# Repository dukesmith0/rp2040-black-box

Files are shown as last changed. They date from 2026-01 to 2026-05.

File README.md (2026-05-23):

# RP2040 Black Box

Flight data logging system using an Adafruit RP2040 microcontroller to capture IMU, GPS, barometric, and magnetometer data at up to 200Hz with Mahony AHRS filtering.

## Hardware

| Component | Description |
|---|---|
| Adafruit Feather RP2040 Adalogger | Main board with SD card slot |
| Adafruit BMP390 | Barometric altimeter (50Hz) |
| Adafruit LSM6DSOX | 6-DOF accelerometer/gyroscope (208Hz) |
| Adafruit LIS3MDL | 3-axis magnetometer (155Hz) |
| Adafruit Mini GPS PA1010D | GPS module (10Hz) |

### Hardware Guides
- [Adafruit Feather RP2040 Adalogger](https://learn.adafruit.com/adafruit-feather-rp2040-adalogger/overview)
- [Adafruit BMP390](https://learn.adafruit.com/adafruit-bmp388-bmp390-bmp3xx/overview)
- [Adafruit Mini GPS PA1010D](https://learn.adafruit.com/adafruit-mini-gps-pa1010d-module/overview)
- [Adafruit LSM6DSOX + LIS3MDL 9-DOF](https://learn.adafruit.com/st-9-dof-combo/overview)

### Enclosure

The second enclosure revision features a full case for better protection and improved battery mounting.

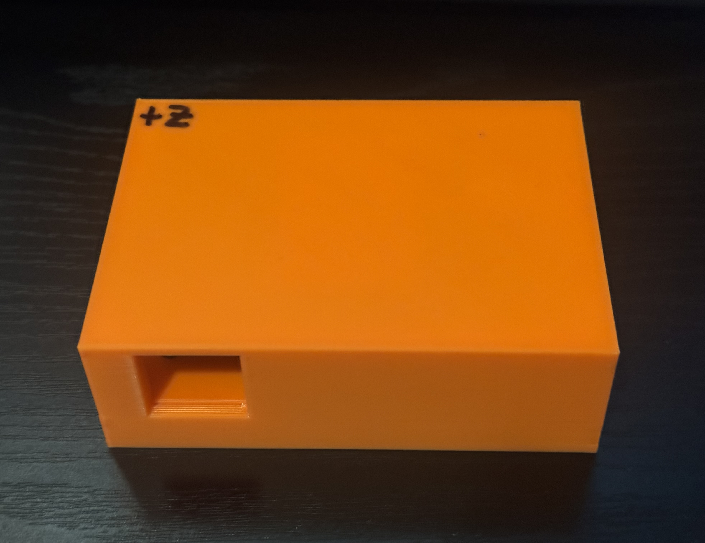
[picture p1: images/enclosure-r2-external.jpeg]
Enclosure R2 external

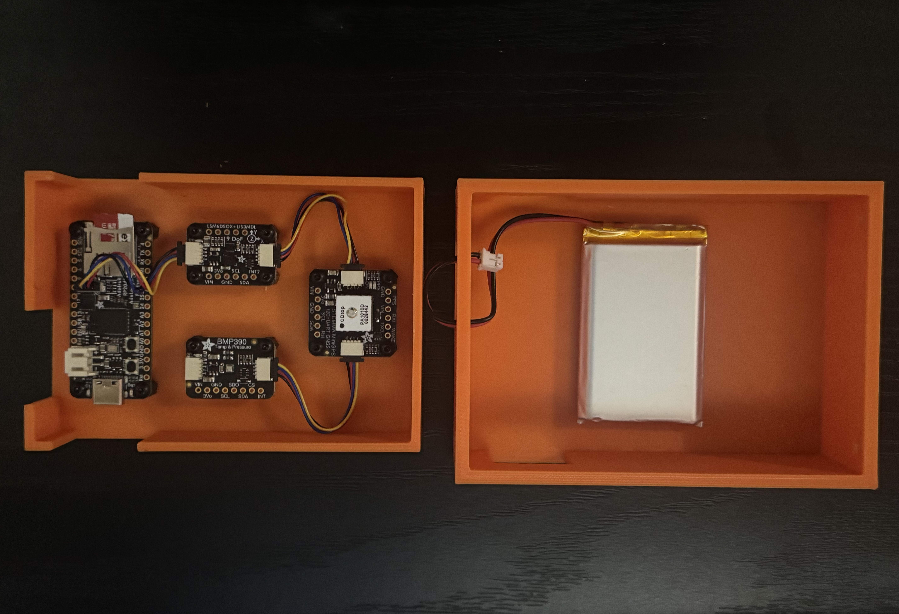
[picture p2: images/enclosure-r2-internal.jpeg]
Enclosure R2 internal


| Part | Quantity |
|---|---|
| M2.5 heat inserts | 14 |
| M2.5 6mm standoffs | 12 |
| M2.5 6mm screws | 12 |
| M3 heat inserts | 4 |
| M3 6mm standoffs | 4 |
| M3 6mm screws | 4 |
| 50mm STEMMA QT cable | 3 |
| 32GB SD card (FAT32) | 1 |
| 3.7V 2000mAh LiPo battery (2-pin JST-PH) | 1 |
| Hot glue | - |

### Estimated Cost

| Item | Est. Price |
|---|---|
| Adafruit Feather RP2040 Adalogger | $14.95 |
| Adafruit BMP390 | $10.95 |
| Adafruit LSM6DSOX + LIS3MDL 9-DOF IMU | $19.95 |
| Adafruit Mini GPS PA1010D | $29.95 |
| STEMMA QT 50mm cables (×3) | $2.85 |
| 32GB microSD card | ~$8 |
| 3.7V 2000mAh LiPo battery | $12.50 |
| 3D printed enclosure (PLA filament) | ~$3 |
| M2.5/M3 hardware (heat inserts, standoffs, screws) | ~$10 |
| Hot glue | ~$1 |
| **Total** | **~$113** |

> Prices based on Adafruit retail (single-unit) as of early 2026. SD card and hardware prices vary by vendor.

---

## Getting Started

### Arduino Setup

Add this URL to Arduino IDE > File > Preferences > Additional Boards Manager URLs:
```
https://github.com/earlephilhower/arduino-pico/releases/download/global/package_rp2040_index.json
```

Install **Raspberry Pi Pico/RP2040/RP2350** by Earle F. Philhower, III

Select board: **Tools > Boards > Raspberry Pi Pico RP2040/RP2350 > Adafruit Feather RP2040 Adalogger**

> Note: If no serial port appears, that's normal - RP2040 uses USB bootloader. A port will appear after first upload.

### Arduino Libraries

Install via Library Manager (Tools > Manage Libraries):

| Library | Purpose |
|---|---|
| **SdFat** | SD card operations |
| **Adafruit BMP3XX** | BMP390 altimeter |
| **Adafruit GPS Library** | PA1010D GPS |
| **Adafruit LIS3MDL** | Magnetometer |
| **Adafruit LSM6DSOX** | Accelerometer/Gyroscope |
| **Adafruit AHRS** | Mahony sensor fusion |
| **Adafruit Unified Sensor** | Common sensor interface (dependency) |
| **Adafruit BusIO** | I2C/SPI helper (dependency) |

> **Important:** This project uses the `SdFat` library (not the standard Arduino `SD.h`) for proper RP2040 Adalogger hardware support.

### SD Card

**Hardware configuration:**
- **CS Pin:** 23 (NOT pin 10!)
- **SPI Bus:** SPI1 @ 16MHz
- **Library:** SdFat (configured automatically in firmware)

**Requirements:**
- Format: FAT32 with 4KB allocation unit size
- Works with most SD/SDHC cards

**Troubleshooting:**
If SD initialization fails, check that the card is inserted and formatted as FAT32 with 4KB allocation units. Try cleaning the contacts or using a different card. The firmware retries 5 times automatically. Use `firmware/test/sd_card_tester/` to diagnose issues.

---

## Firmware

### quat_datalogger

Dual-core flight data logger with real-time AHRS filtering and signal processing.

Serial Data

**Core 0** reads sensors and logs to SD at 100Hz. **Core 1** runs the Mahony AHRS filter at 200Hz.

**Signal processing pipeline:**
- Adaptive Mahony filter (Kp ramps 10.0 → 1.0, Ki = 0.008 for drift correction)
- Sensor calibration: magnetometer hard/soft iron, gyro auto-cal at boot, accelerometer offsets
- Altitude: BMP390 hardware IIR → software low-pass filter → GPS complementary filter
- Auto sea-level pressure calibration from first good GPS fix
- GPS quality rejection (min satellites, max HDOP) with low-pass filtered speed/heading
- Automatic file splitting every ~1 GB to stay under FAT32 4 GB limit

Calibration constants are loaded from `calibration.cfg` on the SD card at boot (see [Calibration](#calibration)). Filter tuning parameters are editable at the top of the firmware file.

### Calibration Sketches

Two standalone sketches in `firmware/calibration/` for computing sensor calibration values:

- **magnetometer_calibration**: Streams `Raw:` / `Uni:` data over serial in the format expected by [MotionCal](https://www.pjrc.com/store/prop_shield.html). Rotate the device in all orientations until the sphere fills in, then copy the hard/soft iron values into `calibration.cfg`.
- **accelerometer_calibration**: Interactive serial-guided 6-position calibration. Prompts you through each orientation, collects samples, and writes the computed offsets directly to `calibration.cfg` on the SD card.

### diagnostic

Serial and sensor diagnostic tool that tests each I2C sensor individually with detailed bus diagnostics. Upload and open Serial Monitor at 115200 baud to verify all sensors are detected and responding correctly.

### sd_card_tester

Diagnostic tool for verifying SD card compatibility. Tests initialization, read/write, and speed benchmarking.

---

## Data Format

**Output:** 20-column CSV at 100Hz

| Column | Description | Units |
|---|---|---|
| ms | Timestamp | milliseconds |
| qw, qx, qy, qz | Orientation quaternion | - |
| ax, ay, az | Acceleration | m/s² |
| gx, gy, gz | Angular velocity | rad/s |
| mx, my, mz | Magnetic field | uT |
| alt | Filtered altitude | meters |
| gps_fix | GPS lock status | 0/1 |
| lat, lon | GPS coordinates | decimal degrees |
| speed | Filtered GPS speed | knots |
| heading | Filtered GPS heading | degrees |

**File naming:** Timestamps use UTC from the GPS module's battery-backed RTC.
- GPS time available: `20260130_143022_0.csv`, `..._1.csv`, `..._2.csv`
- GPS time unavailable: `log0_0.csv`, `log0_1.csv`, ...
- Header: `# Start: YYYY-MM-DDTHH:MM:SS UTC`

---

## Calibration

Calibration values are stored in a `calibration.cfg` file on the SD card. The firmware reads this file at boot and applies the values automatically. If the file is missing, compiled defaults (zeros / identity) are used.

### 0. Gyroscope Bias (automatic)

The firmware averages 500 samples at boot while stationary. Keep the device still for 5 seconds after power-on. The computed bias is printed to serial.

To skip the wait, note the printed values and hardcode them in the firmware:
```cpp
static const bool GYRO_AUTO_CAL = false;
static float gyro_bias[3] = { -0.0023f, 0.0041f, -0.0012f };
```

### 1. Magnetometer Hard/Soft Iron (critical for heading accuracy)

This is the most important calibration. Without it, heading (yaw) will be unreliable.

1. Upload `firmware/calibration/magnetometer_calibration/` to the board
2. Open [MotionCal](https://www.pjrc.com/store/prop_shield.html) and select the serial port
3. Slowly rotate the device through all orientations (figure-8 pattern) until the sphere fills in
4. Read the values from MotionCal and add them to a new file called `calibration.cfg` in the root of the SD card, using this format:
```
mag_hard_iron = <X>, <Y>, <Z>
mag_soft_iron = <M00>, <M01>, <M02>, <M10>, <M11>, <M12>, <M20>, <M21>, <M22>
```

Do this calibration with the device in its final enclosure. Nearby metal magnets, and mechanical stresses may affect the result.

### 2. Accelerometer Offsets

1. Upload `firmware/calibration/accelerometer_calibration/` to the board
2. Open Serial Monitor at 115200 baud
3. Follow the prompts: place the device in each of 6 orientations (X up/down, Y up/down, Z up/down) and press Enter
4. Hold the device perfectly still during each 2-second measurement
5. The computed offsets are automatically saved to `calibration.cfg` on the SD card

The sketch preserves any existing entries (e.g., magnetometer values) in the config file.

### 3. Sea-Level Pressure (automatic)

The firmware auto-calibrates from the first good GPS fix. No action needed.

For manual override, add to `calibration.cfg`:
```
sea_level_hpa = 1018.5
```

And optionally disable auto-cal in the firmware:
```cpp
static const bool BARO_GPS_AUTO_CAL = false;
```

### 4. Validation

After calibrating, run these checks on the quat_datalogger.ino firmware.

| Test | Procedure | Expected Result |
|---|---|---|
| Static | Place flat and still for 30s after boot | Quaternion settles to ~[1, 0, 0, 0] |
| Rotation | Rotate 90° and return | Quaternion returns to original value |
| GPS walk | Walk a known rectangle outdoors | Lat/lon tracks your path, altitude is stable |

---

## Visualization

### Flight Visualizer (Streamlit)

Interactive web-based visualization.

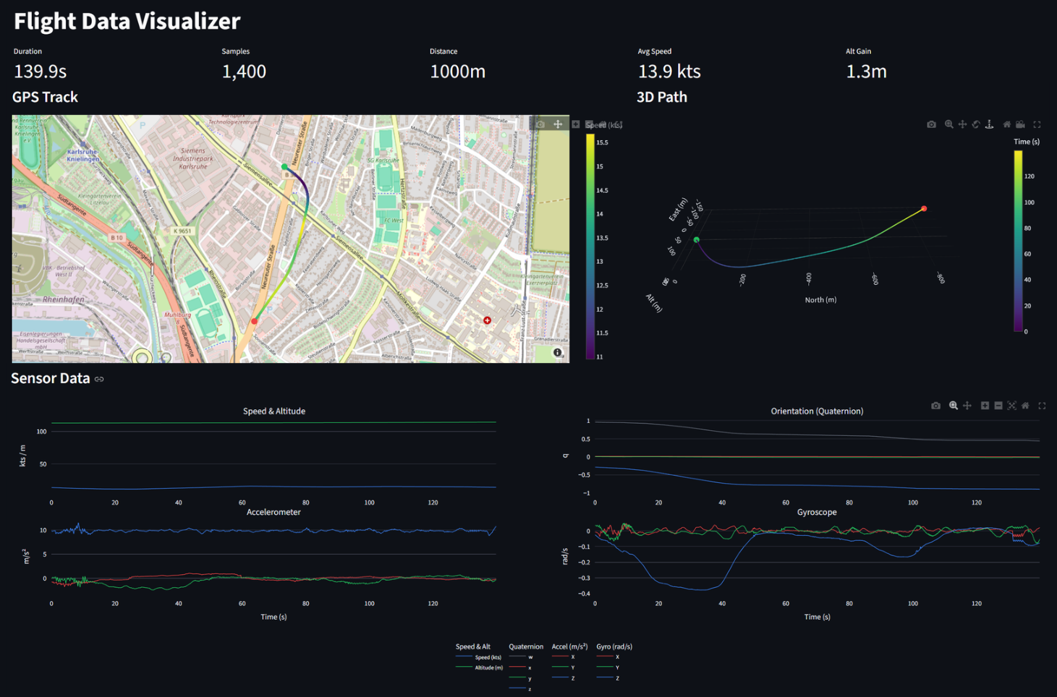
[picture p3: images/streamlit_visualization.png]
Streamlit Visualization


```bash
pip install streamlit pandas numpy plotly scipy
cd software/flight_visualizer
streamlit run app.py
```

Live demo: **[rp2040-fdr-visualizer.streamlit.app](https://rp2040-fdr-visualizer.streamlit.app/)**

### Trajectory Visualizer (MATLAB)

Desktop visualization with satellite map overlays, dead reckoning, and sensor charts. Requires MATLAB with **Navigation Toolbox** (`quaternion`, `rotateframe`).

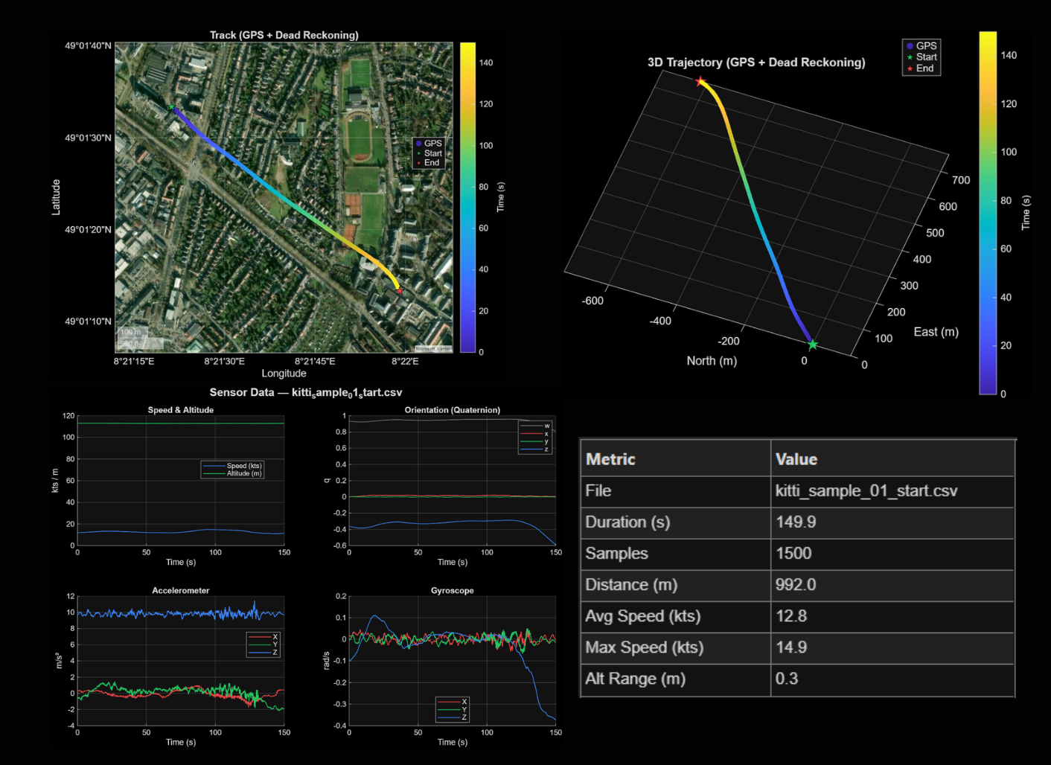
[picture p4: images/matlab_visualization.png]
Matlab Visualization


```
Open MATLAB, navigate to software/matlab-visualizer/, run trajectoryvisualizer.m
```

A file picker dialog opens. Select any 20-column CSV from `data/samples/` or from the SD card.

**Displays:**
- Summary statistics popup (duration, distance, speed, altitude range)
- 2D GPS + dead-reckoned track on satellite basemap (time-gradient colored, circle markers for GPS, diamond markers for dead reckoned)
- 3D trajectory with gradient-colored line (North/East/Altitude in meters)
- 4-panel sensor charts: Speed & Altitude, Quaternion, Accelerometer, Gyroscope

When GPS fix is lost, the visualizer dead-reckons position by rotating body-frame acceleration to NED using the quaternion, subtracting gravity, and integrating velocity/position. Barometric altitude is used for the vertical axis throughout.

### Live Orientation Visualizer (MATLAB)

Real-time 3D orientation display from live serial data. Connects to the RP2040 over USB and renders orientation using `poseplot`. Requires MATLAB with **Navigation Toolbox** and R2019b+ (`serialport`).

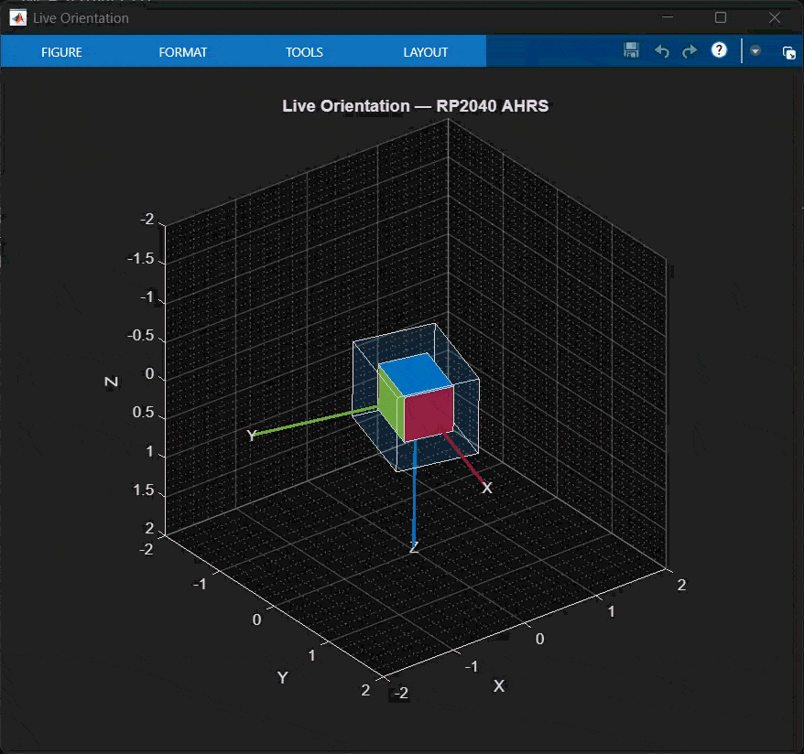
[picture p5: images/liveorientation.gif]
Live Orientation


```
Open MATLAB, navigate to software/matlab-visualizer/, run liveorientationvisualizer.m
```

Select a serial port and baud rate (default 115200) when prompted. The figure updates in real time as the device streams quaternion data. Close the figure window to disconnect.

---

## Future Plans

### Enclosure
- Ruggedize with TPU secondary enclosure for crash survivability

### Hardware
- Upgrade GPS module to use a larger antenna for better signal
- Design custom PCB integrating RP2040 and all sensors onto a single board
- Add Bluetooth for wireless flight data streaming
- **Consider BNO085 IMU**: Replace LSM6DSOX + LIS3MDL with BNO085 for onboard hardware EKF fusion, reducing CPU load with hardware-accelerated quaternion output and automatic calibration

### Power & Monitoring
- Optimize battery usage and create power consumption metrics
- Add internal telemetry: battery life, board temperature

### Software
- Add Simulink visualization for real-time 3D flight simulation and analysis

---

## Previous Iterations

### Enclosure R1

The first enclosure prototype. Open-top design with standoff-mounted boards.

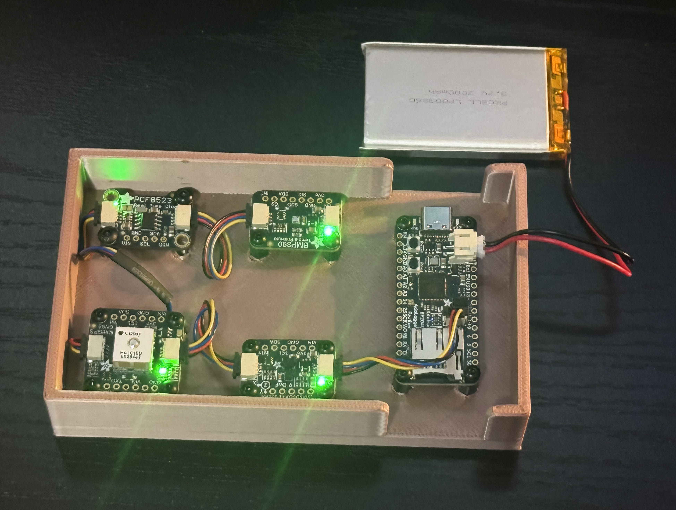
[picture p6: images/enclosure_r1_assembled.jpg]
Enclosure R1 assembled


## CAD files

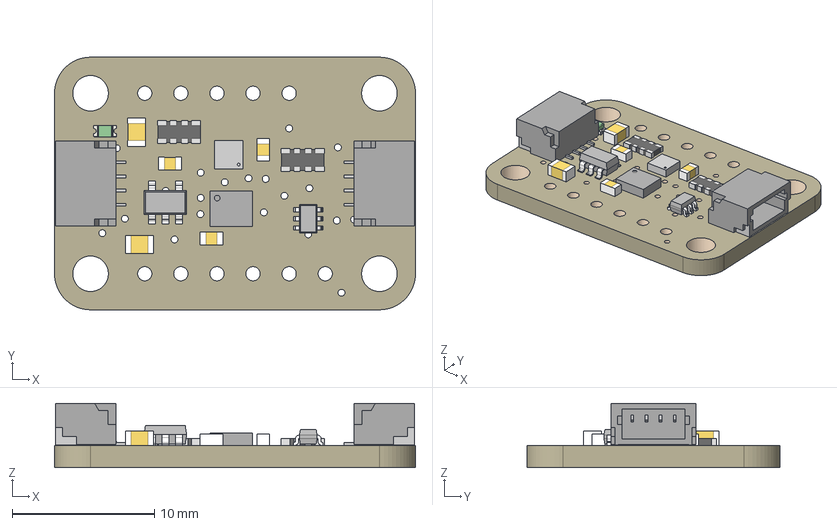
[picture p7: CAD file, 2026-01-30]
hardware/boards/4517_LSM6DSOX_LIS3MDL.step
25.4 x 17.8 x 4.53 mm
Board
10uF x 2
AP2112K-3.3
1uF x 3
10K x 2
BSS138
STEMMA_I2C_QT x 2
GREEN
LIS3MDL
LSM6DSOX

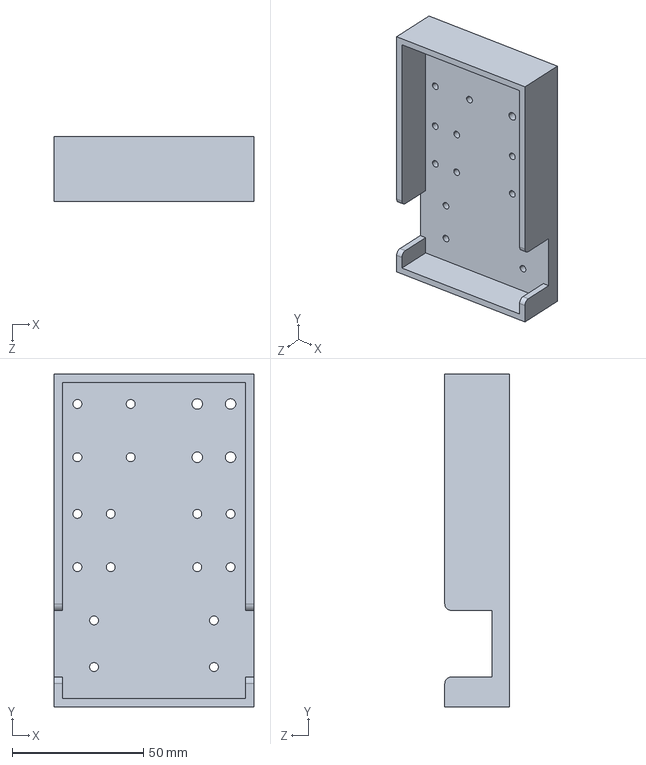
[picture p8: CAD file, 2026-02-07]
hardware/enclosure-r1/enclosure-r1.STEP
76.2 x 127.0 x 24.6 mm

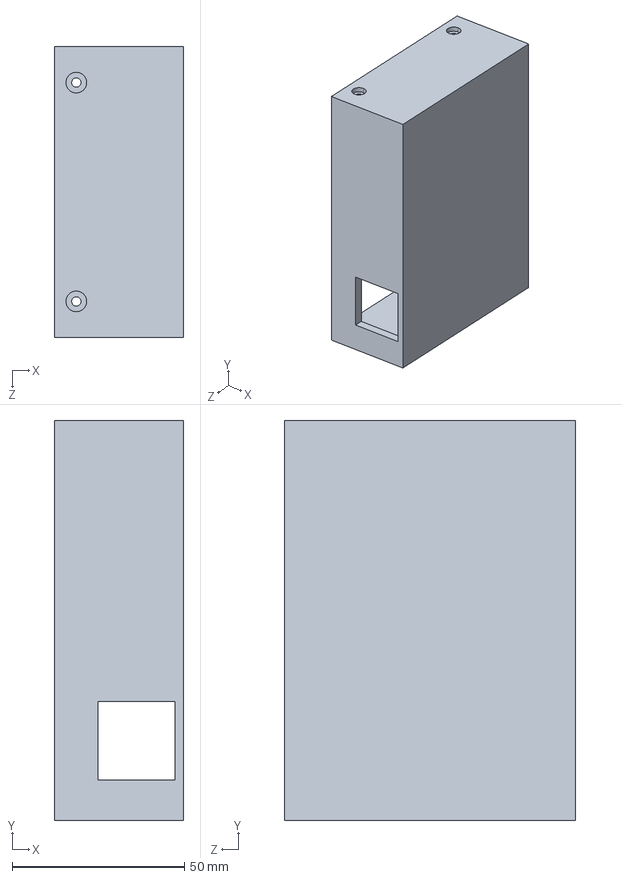
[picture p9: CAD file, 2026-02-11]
hardware/enclosure-r2/top.STEP
37.5 x 116.1 x 84.3 mm

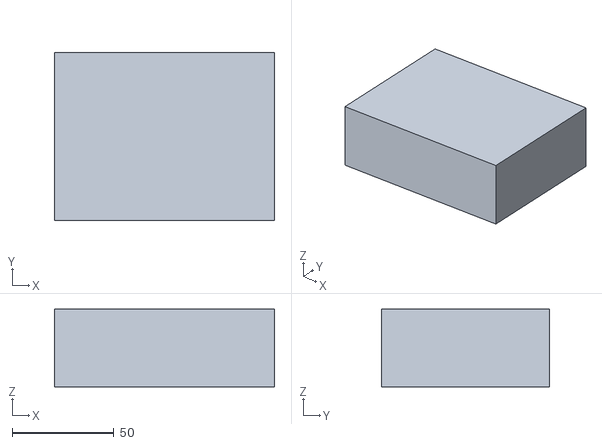
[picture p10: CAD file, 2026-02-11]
software/matlab-visualizer/visualizer_placeholders/enclosure_r2_ph.stl
107.9 x 82.6 x 38.1

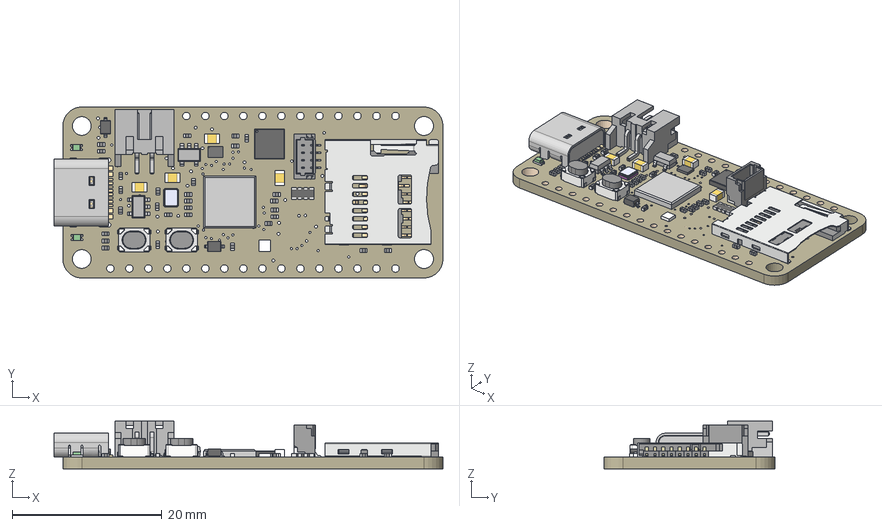
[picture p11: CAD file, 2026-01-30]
hardware/boards/5980_Feather_RP2040_Adalogger.step
52.0 x 22.9 x 6.37 mm
Board
10uF/16V x 4
ORANGE x 2
47K x 29
RKB2 x 2
RT9080-3.3
JSTPH
MCP73831T-2ACI/OT
WS2812B_SK6805_1515
8MB QSPI
PMEG2020AEA
DMG3415UFY
USB Type C
RP2040_QFN56
12MHz/12pF
1N5819
STEMMA_I2C_QTRA
MicroSD
47K_1

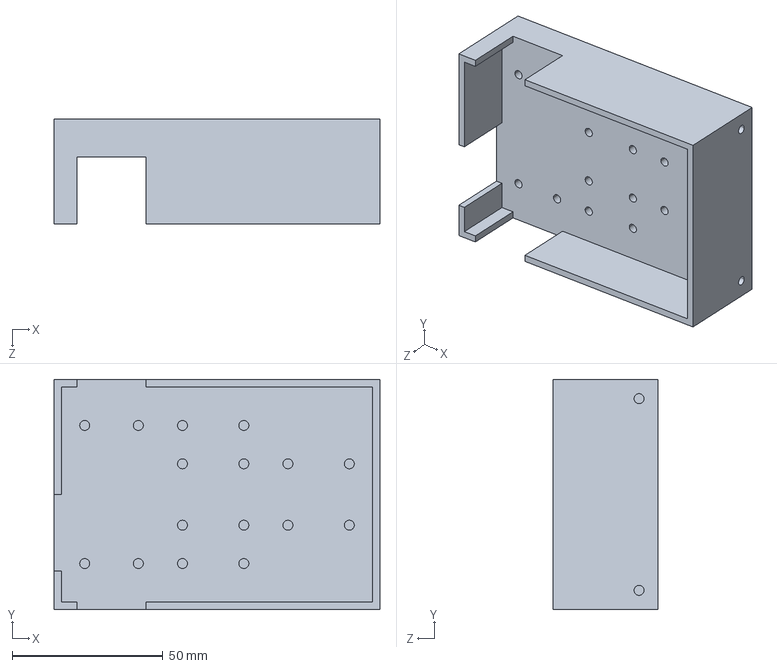
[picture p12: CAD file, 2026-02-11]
hardware/enclosure-r2/base.STEP
107.9 x 76.2 x 34.9 mm

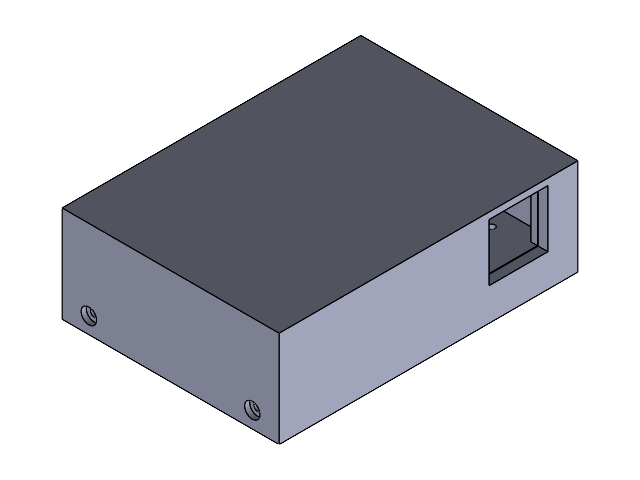
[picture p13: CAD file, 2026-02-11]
hardware/enclosure-r2/assembly.SLDASM
base
top

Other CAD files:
hardware/boards/4816_BMP390_QT.step
hardware/enclosure-r1/enclosure-r1.SLDPRT
hardware/enclosure-r2/base.SLDPRT
hardware/enclosure-r2/top.SLDPRT

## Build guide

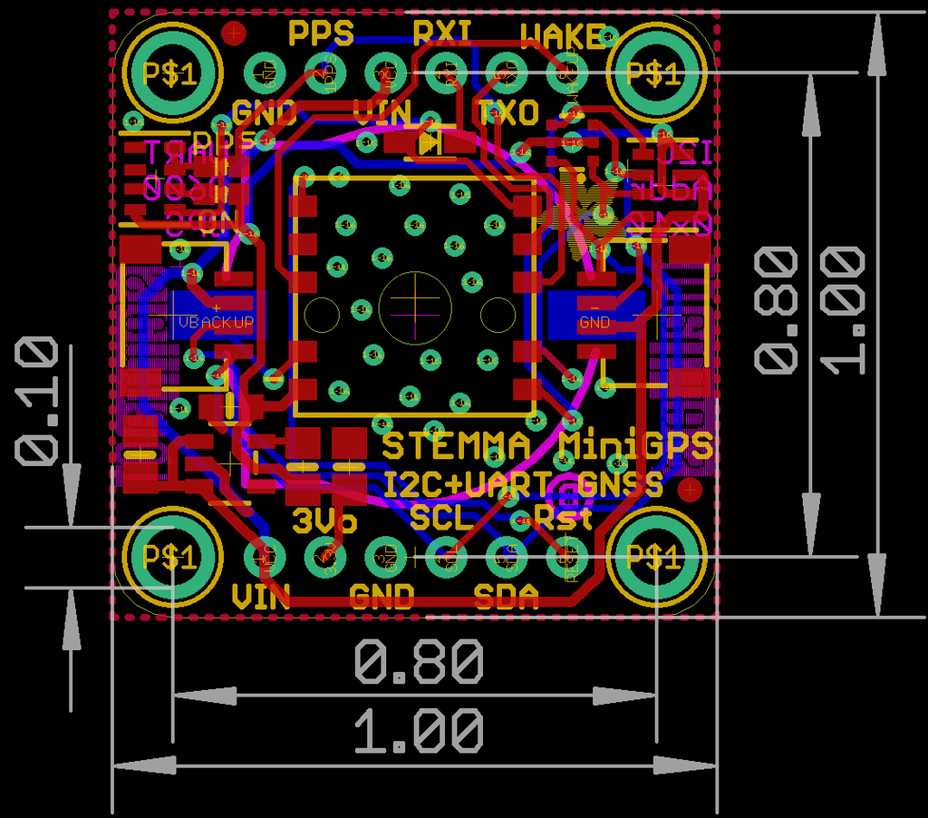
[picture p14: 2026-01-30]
hardware/boards/mini_gps_PA1010D_fab_print.png

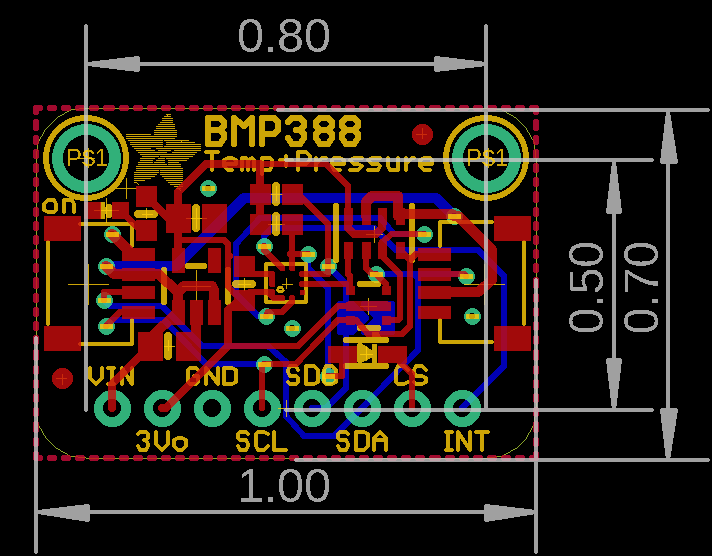
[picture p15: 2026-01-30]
hardware/boards/barometer_altimeter_BMP390_fab_print.png

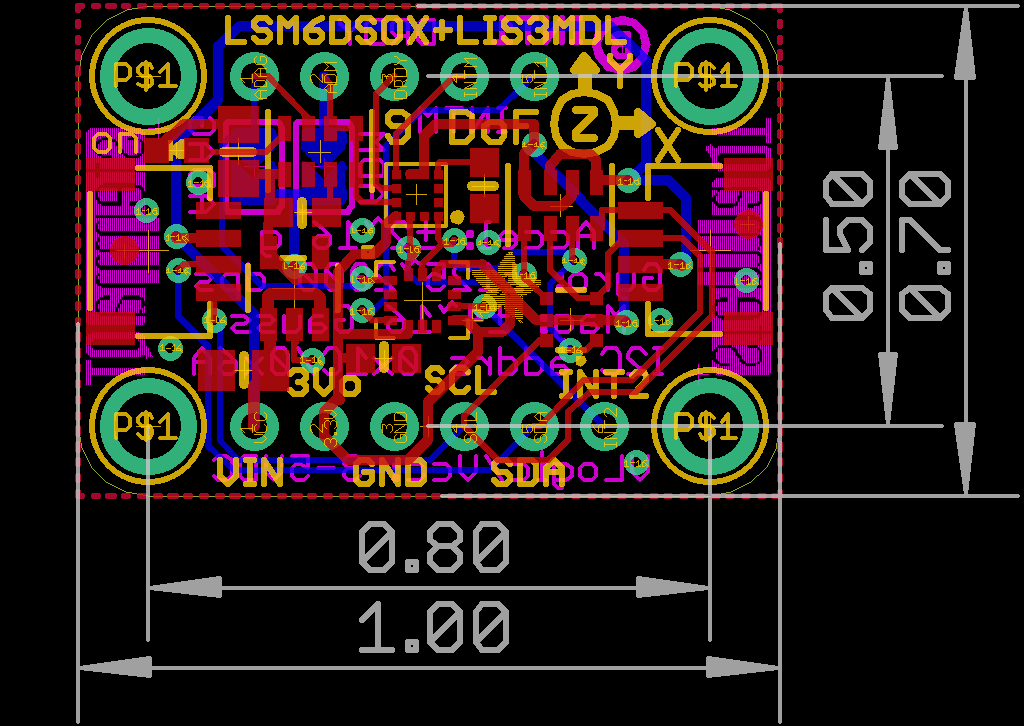
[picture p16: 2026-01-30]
hardware/boards/imu_LSM6DSOX_LIS3MDL_fab_print.png

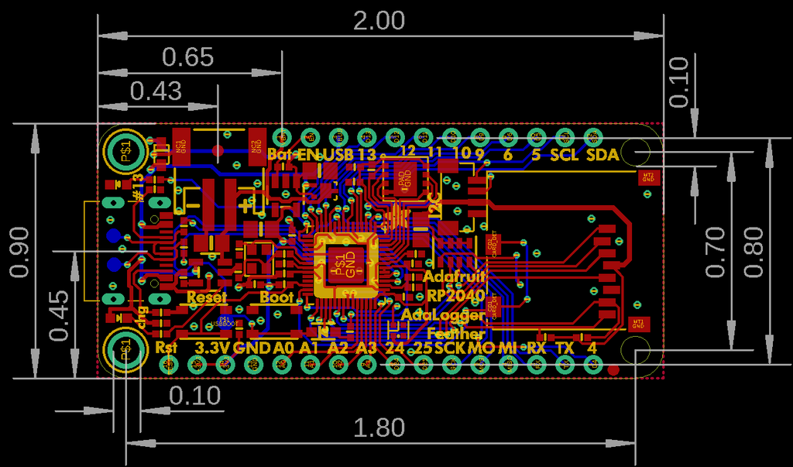
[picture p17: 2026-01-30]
hardware/boards/feather_rp2040_adalogger_fab_print.png

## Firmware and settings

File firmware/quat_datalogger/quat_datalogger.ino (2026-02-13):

/*
  RP2040 Black Box — Mahony AHRS Data Logger (Dual-Core)

  General architecture and output format:

  Core 0: Sensor reading, complementary filtering of altitude/GPS, data logging to SD
  Core 1: Mahony AHRS filter with adaptive gain

  CSV output (20 columns):
    ms, qw, qx, qy, qz, ax, ay, az, gx, gy, gz, mx, my, mz, alt, gps_fix, lat, lon, speed, heading

  File splitting: Creates new CSV every ~1 GB to stay under FAT32 4 GB limit.
*/

#include <Wire.h>
#include <SPI.h>
#include "SdFat.h"
#include <Adafruit_BMP3XX.h>
#include <Adafruit_LSM6DSOX.h>
#include <Adafruit_LIS3MDL.h>
#include <Adafruit_GPS.h>
#include <Adafruit_AHRS.h>

// ============================================================
//  CALIBRATION CONSTANTS — Edit these post calibration (see instructions in README)
// ============================================================

// --- Magnetometer Hard-Iron Offsets (µT) ---
// Measured by rotating device in figure-8 and finding sphere center.
// Use MotionCal (https://learn.adafruit.com/adafruit-sensorlab-magnetometer-calibration/magnetic-calibration-with-motioncal_)
// or log raw mag data and compute in Python/MATLAB.
static float MAG_HARD_IRON[3] = { 0.0f, 0.0f, 0.0f };

// --- Magnetometer Soft-Iron Matrix ---
// Corrects ellipsoid distortion back to a sphere.
// Identity matrix = no correction. Replace with your 3×3 result.
static float MAG_SOFT_IRON[3][3] = {
  { 1.0f, 0.0f, 0.0f },
  { 0.0f, 1.0f, 0.0f },
  { 0.0f, 0.0f, 1.0f }
};

// --- Gyroscope Bias (rad/s) ---
// Measured at startup automatically (average of first N samples at rest).
// You can also hardcode known offsets here and skip auto-cal.
static const bool  GYRO_AUTO_CAL       = true;   // true = auto-calibrate at boot, false = use hardcoded values below
static const int   GYRO_CAL_SAMPLES    = 500;     // Samples to average (500 samples / 100 HZ sample rate = 5 seconds)
static float gyro_bias[3]              = { 0.0f, 0.0f, 0.0f };

// --- Accelerometer Offsets (m/s²) ---
// From 6-position calibration. Subtract from raw readings.
static float ACCEL_OFFSET[3] = { 0.0f, 0.0f, 0.0f };

// --- Barometric Altitude ---
// Set to local sea-level pressure (hPa) for accurate altitude.
// Check weather service before each session, or use GPS auto-cal.
static float       SEA_LEVEL_HPA       = 1013.25f;
static const bool  BARO_GPS_AUTO_CAL   = true;    // Auto-set from first good GPS fix

// ============================================================
//  FILTER TUNING
// ============================================================

// --- Mahony AHRS (Core 1) ---
static const float MAHONY_KP_STARTUP   = 10.0f;   // High gain for fast initial convergence
static const float MAHONY_KP_STEADY    = 1.0f;    // Low gain for smooth steady-state (range: 0.5–1.25)
static const float MAHONY_KI           = 0.008f;  // Integral gain for gyro bias correction (range: 0.005–0.01)
static const float ADAPTIVE_TRANSITION = 5.0f;    // Seconds until Kp drops to steady value

// --- Adaptive Accelerometer Rejection ---
// When accel magnitude deviates from 1g, the accelerometer is sensing non-gravitational
// forces (maneuvers, vibration, impacts). Scale down Kp to rely more on gyro.
static const float ACCEL_1G            = 9.81f;   // Expected gravity magnitude (m/s²)
static const float ACCEL_REJECT_SOFT   = 0.3f;    // Start scaling Kp at this fractional deviation from 1g
static const float ACCEL_REJECT_HARD   = 0.7f;    // Full gyro-only mode at this deviation
static const float ACCEL_REJECT_KP_MIN = 0.02f;   // Minimum Kp during rejection (not zero, avoids drift)

// --- Filter / Logging Rates ---
// Gigher filter rate allows for better sensor fusion, slower update rate means lower CPU load due to SD card writes.
static const int   FILTER_RATE_HZ      = 200;     // AHRS update rate (Core 1), matches IMU 208 Hz
static const int   LOG_RATE_HZ         = 100;     // SD card logging rate (Core 0)
static const int   FILTER_PER_LOG      = FILTER_RATE_HZ / LOG_RATE_HZ;

// --- Altitude Low-Pass Filter ---
// Gets rid of high-frequency noise in barometric altitude. Good for blending with GPS altitude (noisy but stable).
static const float ALT_LPF_ALPHA       = 0.1f;    // 0.0 = no update, 1.0 = no filtering

// --- Altitude Complementary Filter (baro + GPS) ---
static const float ALT_COMP_BARO_WEIGHT = 0.98f;  // Trust baro short-term
// GPS weight = 1.0 - ALT_COMP_BARO_WEIGHT

// --- GPS Low-Pass Filter ---
// Both outputs are noisy, need low pass filtering. 
static const float GPS_SPEED_LPF_ALPHA  = 0.15f;  // Smoothing for GPS speed
static const float GPS_HEADING_LPF_ALPHA = 0.15f;  // Smoothing for GPS heading

// --- GPS Quality Rejection ---
// Reject GPS fixes that don't meet these criteria to avoid contaminating the filter with crappy data.
// Adjust lower if you want to accept more fixes (at the risk of noisier data), or raise if you want only the best fixes (but more dropouts).
static const int   GPS_MIN_SATELLITES   = 4;       // Minimum sats for a "good" fix
static const float GPS_MAX_HDOP         = 5.0f;    // Maximum HDOP for a "good" fix

// ============================================================
//  FILE SPLITTING
// ============================================================

static const uint32_t FILE_SPLIT_BYTES  = 1000000000UL; // ~1 GB per file

// ============================================================
//  HARDWARE OBJECTS
// ============================================================

Adafruit_BMP3XX   bmp;
Adafruit_LSM6DSOX sox;
Adafruit_LIS3MDL  lis3mdl;
Adafruit_GPS      GPS_sensor(&Wire);
Adafruit_Mahony   filter;

// SD card setup from Adafruit RP2040 Adalogger: CS pin 23, SPI1
#define SD_CS_PIN 23
SdFat  SD;
FsFile logFile;
SdSpiConfig sdConfig(SD_CS_PIN, DEDICATED_SPI, SD_SCK_MHZ(16), &SPI1);

// ============================================================
//  SHARED DATA BETWEEN CORES
// ============================================================

// Core 0 to Core 1: raw calibrated sensor data for Mahony filtering, indicator if the data is new.
struct SensorData {
  float ax, ay, az;
  float gx, gy, gz;
  float mx, my, mz;
  volatile bool newData;
};

// Core 1 to Core 0: quaternion output for logging, indicator if quaternion data is ready
struct FilterOutput {
  float qw, qx, qy, qz;
  volatile bool ready;
};

volatile SensorData sensorData   = { 0, 0, 0, 0, 0, 0, 0, 0, 0, false };
volatile FilterOutput filterOutput = { 1.0f, 0, 0, 0, false };

// ============================================================
//  CORE 0 STATE
// ============================================================

static String   fileBaseName    = "data"; // default naming convention for output files (overridden by GPS time if available)
static String   fileExt         = ".csv"; // defines output file extension
static int      fileSplitIndex  = 0; // number of times file has been split
static uint32_t bytesWritten    = 0; // track bytes for splitting
static bool     gpsTimeValid    = false; // GPS battery-backed RTC time available for filenames
static char     gpsTimestamp[20] = "";   // cached "YYYYMMDD_HHMMSS" from GPS RTC

// Timing
static uint32_t lastSampleTime  = 0; // For main loop timing, filter update rate
static int      filterTickCount = 0; // Counts filter ticks to decimate for logging

// Filtered altitude state
static float    altFiltered     = 0.0f; // complementary filter output for altitude (baro + GPS)
static bool     altInitialized  = false; // flag to initialize altFiltered on first run
static float    lastBaroAlt     = 0.0f; // Last raw barometric altitude reading for complementary filter

// Filtered GPS state
static float    gpsSpeedFiltered   = 0.0f; // low-pass filtered GPS speed for smoother output
static float    gpsHeadingFiltered = 0.0f; // low-pass filtered GPS heading for smoother output (handles 0/360 wraparound)
static bool     gpsFilterInit      = false; // flag to initialize GPS filters on first good fix
static bool     baroPressureCaled  = false; // flag to indicate if barometric pressure has been auto-calibrated from GPS altitude

// Baro read decimation (BMP390 runs at 50 Hz, main loop at 200 Hz → read every 4th tick)
static const int BARO_DECIMATION = FILTER_RATE_HZ / 50; // Counter to track when to read barometer
static int       baroTickCount   = 0; // Counts main loop ticks to decimate barometer reads

// ============================================================
//  CORE 1: Mahony AHRS Filter with Adaptive Gain
// ============================================================

// setting up and adding filter variables previosuly declared as global volatile
void setup1() {
  filter.begin(FILTER_RATE_HZ);
  filter.setKp(MAHONY_KP_STARTUP);
  filter.setKi(MAHONY_KI);
}

// If there is sensor data, copy it locally and run the Mahony filter update, then publish the quaternion output for logging.
void loop1() {
  if (!sensorData.newData) return;

  // Copy shared data locally
  float ax = sensorData.ax;
  float ay = sensorData.ay;
  float az = sensorData.az;
  float gx = sensorData.gx;
  float gy = sensorData.gy;
  float gz = sensorData.gz;
  float mx = sensorData.mx;
  float my = sensorData.my;
  float mz = sensorData.mz;
  sensorData.newData = false;

  // --- ADAPTIVE GAIN (startup ramp) ---
  // Ramp Kp from startup value down to steady value over ADAPTIVE_TRANSITION seconds
  float elapsed = millis() / 1000.0f;
  float baseKp;
  if (elapsed < ADAPTIVE_TRANSITION) {
    float t = elapsed / ADAPTIVE_TRANSITION;               // 0 → 1
    baseKp = MAHONY_KP_STARTUP + t * (MAHONY_KP_STEADY - MAHONY_KP_STARTUP);
  } else {
    baseKp = MAHONY_KP_STEADY;
  }

  // --- ADAPTIVE ACCELEROMETER REJECTION ---
  // When accel magnitude deviates from 1g, non-gravitational forces are present.
  // Scale Kp down so the filter trusts gyro more during dynamic maneuvers.
  float accelMag = sqrtf(ax * ax + ay * ay + az * az);
  float deviation = fabsf(accelMag - ACCEL_1G) / ACCEL_1G;  // Fractional deviation from 1g

  float kp;
  if (deviation <= ACCEL_REJECT_SOFT) {
    kp = baseKp;                                             // Normal operation
  } else if (deviation >= ACCEL_REJECT_HARD) {
    kp = ACCEL_REJECT_KP_MIN;                                // Full rejection (gyro-only)
  } else {
    // Linear interpolation between soft and hard thresholds
    float t = (deviation - ACCEL_REJECT_SOFT) / (ACCEL_REJECT_HARD - ACCEL_REJECT_SOFT);
    kp = baseKp + t * (ACCEL_REJECT_KP_MIN - baseKp);
  }
  filter.setKp(kp);

  // Convert gyro from rad/s → deg/s (Adafruit AHRS expects deg/s)
  float gx_dps = gx * SENSORS_RADS_TO_DPS;
  float gy_dps = gy * SENSORS_RADS_TO_DPS;
  float gz_dps = gz * SENSORS_RADS_TO_DPS;

  // MAHONY FILTER UPDATE
  filter.update(gx_dps, gy_dps, gz_dps, ax, ay, az, mx, my, mz);

  // Publish quaternion
  float qw, qx, qy, qz;
  filter.getQuaternion(&qw, &qx, &qy, &qz);
  filterOutput.qw = qw;
  filterOutput.qx = qx;
  filterOutput.qy = qy;
  filterOutput.qz = qz;
  filterOutput.ready = true;
}

// ============================================================
//  CORE 0: Sensor Reading and Data Logging
// ============================================================

// --- Helper: Load calibration from SD card config file ---
// Reads "calibration.cfg" from SD root. Falls back to compiled defaults if missing.
// Format: key = value (comma-separated floats). Lines starting with # are comments.
static const char* CAL_FILENAME = "calibration.cfg";

static bool parseFloats(const char* str, float* out, int count) {
  for (int i = 0; i < count; i++) {
    char* end;
    out[i] = strtof(str, &end);
    if (end == str) return false; // parse failure
    str = end;
    // Skip comma and whitespace
    while (*str == ',' || *str == ' ' || *str == '\t') str++;
  }
  return true;
}

static void loadCalibration() {
  if (!SD.exists(CAL_FILENAME)) {
    Serial.println("No calibration.cfg found, using defaults.");
    return;
  }

  FsFile cfg = SD.open(CAL_FILENAME, FILE_READ);
  if (!cfg) {
    Serial.println("Failed to open calibration.cfg, using defaults.");
    return;
  }

  Serial.println("Loading calibration.cfg...");
  int loaded = 0;
  char line[256];

  while (cfg.available()) {
    // Read one line
    int len = 0;
    while (cfg.available() && len < (int)sizeof(line) - 1) {
      char c = cfg.read();
      if (c == '\n') break;
      if (c != '\r') line[len++] = c;
    }
    line[len] = '\0';

    // Skip empty lines and comments
    if (len == 0 || line[0] == '#') continue;

    // Find '=' separator
    char* eq = strchr(line, '=');
    if (!eq) continue;

    // Split key and value
    *eq = '\0';
    char* key = line;
    char* val = eq + 1;

    // Trim trailing spaces from key
    char* kend = eq - 1;
    while (kend > key && (*kend == ' ' || *kend == '\t')) *kend-- = '\0';

    // Trim leading spaces from value
    while (*val == ' ' || *val == '\t') val++;

    // Match keys
    if (strcmp(key, "mag_hard_iron") == 0) {
      if (parseFloats(val, MAG_HARD_IRON, 3)) {
        Serial.print("  mag_hard_iron = ");
        Serial.print(MAG_HARD_IRON[0], 4); Serial.print(", ");
        Serial.print(MAG_HARD_IRON[1], 4); Serial.print(", ");
        Serial.println(MAG_HARD_IRON[2], 4);
        loaded++;
      }
    } else if (strcmp(key, "mag_soft_iron") == 0) {
      float flat[9];
      if (parseFloats(val, flat, 9)) {
        for (int r = 0; r < 3; r++)
          for (int c = 0; c < 3; c++)
            MAG_SOFT_IRON[r][c] = flat[r * 3 + c];
        Serial.println("  mag_soft_iron = (3x3 matrix loaded)");
        loaded++;
      }
    } else if (strcmp(key, "accel_offset") == 0) {
      if (parseFloats(val, ACCEL_OFFSET, 3)) {
        Serial.print("  accel_offset = ");
        Serial.print(ACCEL_OFFSET[0], 4); Serial.print(", ");
        Serial.print(ACCEL_OFFSET[1], 4); Serial.print(", ");
        Serial.println(ACCEL_OFFSET[2], 4);
        loaded++;
      }
    } else if (strcmp(key, "sea_level_hpa") == 0) {
      float v;
      if (parseFloats(val, &v, 1) && v > 800.0f && v < 1200.0f) {
        SEA_LEVEL_HPA = v;
        Serial.print("  sea_level_hpa = ");
        Serial.println(SEA_LEVEL_HPA, 2);
        loaded++;
      }
    }
  }

  cfg.close();
  Serial.print("Calibration loaded (");
  Serial.print(loaded);
  Serial.println(" values).");
}

// --- Helper, build split filename ---
static String buildFileName() {
  return fileBaseName + "_" + String(fileSplitIndex) + fileExt;
}

// --- Helper, open a new log file (or next split) ---
static bool openLogFile() {
  if (logFile) {
    logFile.close();
  }

  String name = buildFileName();
  logFile = SD.open(name.c_str(), FILE_WRITE);
  if (!logFile) {
    Serial.print("Failed to open: ");
    Serial.println(name);
    return false;
  }

  // Write timestamp header from GPS RTC if available
  if (gpsTimeValid) {
    char ts[50];
    snprintf(ts, sizeof(ts), "# Start: %.4s-%.2s-%.2sT%.2s:%.2s:%.2s UTC",
             gpsTimestamp, gpsTimestamp + 4, gpsTimestamp + 6,
             gpsTimestamp + 9, gpsTimestamp + 11, gpsTimestamp + 13);
    logFile.println(ts);
  }
  // Header line for CSV columns
  logFile.println("ms,qw,qx,qy,qz,ax,ay,az,gx,gy,gz,mx,my,mz,alt,gps_fix,lat,lon,speed,heading");
  logFile.flush(); // ensure header is written immediately
  bytesWritten = 0;

  Serial.print("Logging to: ");
  Serial.println(name);
  return true;
}

// --- Helper: Freaky gyro auto-calibration at startup ---
static void calibrateGyro() {
  Serial.print("Gyro calibration (hold still)...");
  float sum[3] = { 0, 0, 0 };
  sensors_event_t accel, gyro, temp;

  for (int i = 0; i < GYRO_CAL_SAMPLES; i++) {
    sox.getEvent(&accel, &gyro, &temp);
    sum[0] += gyro.gyro.x;
    sum[1] += gyro.gyro.y;
    sum[2] += gyro.gyro.z;
    delay(10);
  }

  gyro_bias[0] = sum[0] / GYRO_CAL_SAMPLES;
  gyro_bias[1] = sum[1] / GYRO_CAL_SAMPLES;
  gyro_bias[2] = sum[2] / GYRO_CAL_SAMPLES;

  Serial.print(" done (bias: ");
  Serial.print(gyro_bias[0], 4); Serial.print(", ");
  Serial.print(gyro_bias[1], 4); Serial.print(", ");
  Serial.print(gyro_bias[2], 4); Serial.println(")");
}

// --- Helper: Apply magnetometer calibration (if not done super inaccurate!) ---
static void calibrateMag(float &mx, float &my, float &mz) {
  // Hard-iron removal
  float x = mx - MAG_HARD_IRON[0];
  float y = my - MAG_HARD_IRON[1];
  float z = mz - MAG_HARD_IRON[2];

  // Soft-iron correction
  mx = MAG_SOFT_IRON[0][0] * x + MAG_SOFT_IRON[0][1] * y + MAG_SOFT_IRON[0][2] * z;
  my = MAG_SOFT_IRON[1][0] * x + MAG_SOFT_IRON[1][1] * y + MAG_SOFT_IRON[1][2] * z;
  mz = MAG_SOFT_IRON[2][0] * x + MAG_SOFT_IRON[2][1] * y + MAG_SOFT_IRON[2][2] * z;
}
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
void loop() {
  // --- GPS: Read continuously (non-blocking) ---
  GPS_sensor.read();
  if (GPS_sensor.newNMEAreceived()) {
    GPS_sensor.parse(GPS_sensor.lastNMEA());
  }

  // --- Main Loop at FILTER_RATE_HZ (200 Hz) ---
  uint32_t now = millis();
  if (now - lastSampleTime < (1000 / FILTER_RATE_HZ)) return;
  lastSampleTime += (1000 / FILTER_RATE_HZ);
  if (now - lastSampleTime > (1000 / FILTER_RATE_HZ)) {
    lastSampleTime = now;  // Guard against falling behind
  }

  // ---- READ IMU SENSORS ----
  sensors_event_t accel, gyro, temp, mag;
  sox.getEvent(&accel, &gyro, &temp);
  lis3mdl.getEvent(&mag);

  // ---- APPLY CALIBRATION ----

  // Accelerometer offset
  float ax = accel.acceleration.x - ACCEL_OFFSET[0];
  float ay = accel.acceleration.y - ACCEL_OFFSET[1];
  float az = accel.acceleration.z - ACCEL_OFFSET[2];

  // Gyroscope bias removal
  float gx = gyro.gyro.x - gyro_bias[0];
  float gy = gyro.gyro.y - gyro_bias[1];
  float gz = gyro.gyro.z - gyro_bias[2];

  // Magnetometer hard/soft iron correction
  float mx = mag.magnetic.x;
  float my = mag.magnetic.y;
  float mz = mag.magnetic.z;
  calibrateMag(mx, my, mz);

  // ---- PASS TO CORE 1 (AHRS MAHONY FILTER) ----
  sensorData.ax = ax;
  sensorData.ay = ay;
  sensorData.az = az;
  sensorData.gx = gx;
  sensorData.gy = gy;
  sensorData.gz = gz;
  sensorData.mx = mx;
  sensorData.my = my;
  sensorData.mz = mz;
  sensorData.newData = true;

  // ---- READ BAROMETER (decimated to ~50 Hz) ----
  baroTickCount++;
  if (baroTickCount >= BARO_DECIMATION) {
    baroTickCount = 0;
    if (bmp.performReading()) {
      lastBaroAlt = 44330.0f * (1.0f - powf((bmp.pressure / 100.0f) / SEA_LEVEL_HPA, 0.1903f));
    }
  }

  // ---- ALTITUDE LOW-PASS FILTER ----
  if (!altInitialized) {
    altFiltered = lastBaroAlt;
    altInitialized = true;
  } else {
    altFiltered = ALT_LPF_ALPHA * lastBaroAlt + (1.0f - ALT_LPF_ALPHA) * altFiltered;
  }

  // ---- ALTITUDE COMPLEMENTARY FILTER (baro + GPS) ----
  if (isGpsGoodFix() && GPS_sensor.altitude > 0.0f) {
    float gpsAlt = GPS_sensor.altitude;
    altFiltered = ALT_COMP_BARO_WEIGHT * altFiltered
                + (1.0f - ALT_COMP_BARO_WEIGHT) * gpsAlt;

    // Auto-calibrate sea-level pressure from first good GPS fix
    if (BARO_GPS_AUTO_CAL && !baroPressureCaled) {
      // Reverse the barometric formula: P0 = P / (1 - alt/44330)^5.255 , thanks to Wikipedia
      float rawPressure = bmp.pressure / 100.0f;  // Pa to hPa
      float ratio = 1.0f - (gpsAlt / 44330.0f);
      if (ratio > 0.0f && rawPressure > 300.0f && rawPressure < 1200.0f) {
        float calP0 = rawPressure / powf(ratio, 5.255f);
        if (calP0 > 800.0f && calP0 < 1200.0f) {
          SEA_LEVEL_HPA = calP0;
          baroPressureCaled = true;
          Serial.print("Baro auto-cal: sea level = ");
          Serial.print(SEA_LEVEL_HPA, 2);
          Serial.println(" hPa");
        }
      }
    }
  }

  // ---- GPS SPEED / HEADING LOW-PASS FILTER ----
  bool goodGps = isGpsGoodFix();
  float gpsSpeed   = 0.0f;
  float gpsHeading = 0.0f;
  bool  gpsFix     = false;

  if (goodGps) {
    gpsFix = true;
    float rawSpeed   = GPS_sensor.speed;
    float rawHeading = GPS_sensor.angle;

    if (!gpsFilterInit) {
      gpsSpeedFiltered   = rawSpeed;
      gpsHeadingFiltered = rawHeading;
      gpsFilterInit      = true;
    } else {
      gpsSpeedFiltered   = GPS_SPEED_LPF_ALPHA * rawSpeed
                         + (1.0f - GPS_SPEED_LPF_ALPHA) * gpsSpeedFiltered;
      gpsHeadingFiltered = lerpAngle(gpsHeadingFiltered, rawHeading, GPS_HEADING_LPF_ALPHA);
    }

    gpsSpeed   = gpsSpeedFiltered;
    gpsHeading = gpsHeadingFiltered;
  }

  // ---- LOG TO SD (decimated to LOG_RATE_HZ) ----
  filterTickCount++;
  if (filterTickCount < FILTER_PER_LOG) return;
  filterTickCount = 0;

  // Get latest quaternion from core 1
  float qw = filterOutput.qw;
  float qx = filterOutput.qx;
  float qy = filterOutput.qy;
  float qz = filterOutput.qz;

  // Build CSV line using char buffer (avoids String heap fragmentation, learned from Adafruit examples and personal experience)
  char line[256];
  int len = snprintf(line, sizeof(line),
    "%lu,%.4f,%.4f,%.4f,%.4f,%.2f,%.2f,%.2f,%.4f,%.4f,%.4f,%.2f,%.2f,%.2f,%.2f,%d,%.6f,%.6f,%.2f,%.2f",
    (unsigned long)millis(),
    qw, qx, qy, qz,
    ax, ay, az,
    gx, gy, gz,
    mx, my, mz,
    altFiltered,
    gpsFix ? 1 : 0,
    gpsFix ? GPS_sensor.latitudeDegrees : 0.0f,
    gpsFix ? GPS_sensor.longitudeDegrees : 0.0f,
    gpsSpeed,
    gpsHeading
  );

  // Serial output
  Serial.println(line);

  // SD output
  if (logFile) {
    logFile.println(line);
    bytesWritten += len + 2;  // +2 for \r\n

    // Flush every second 
    // (data is buffered in RAM and written every second, improving performance but not risking too much data loss)
    static int flushCount = 0;
    if (++flushCount >= LOG_RATE_HZ) {
      logFile.flush();
      flushCount = 0;
    }

    // ---- FILE SPLITTING (every ~1 GB) ----
    if (bytesWritten >= FILE_SPLIT_BYTES) {
      fileSplitIndex++;
      openLogFile();
      Serial.print("Split → file #");
      Serial.println(fileSplitIndex);
    }
  }
}

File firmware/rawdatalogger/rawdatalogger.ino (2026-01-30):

/*
  RP2040 Black Box Data Logger
  Outputs CSV format: ms,qw,qx,qy,qz,ax,ay,az,gx,gy,gz,mx,my,mz,alt,gps_fix,lat,lon,speed,heading
*/

#include <Wire.h>
#include <SPI.h>
#include <SD.h>
#include <Adafruit_BMP3XX.h>
#include <Adafruit_LSM6DSOX.h>
#include <Adafruit_LIS3MDL.h>
#include <Adafruit_GPS.h>
#include <Adafruit_AHRS.h>

// Sensors
Adafruit_BMP3XX bmp;
Adafruit_LSM6DSOX sox;
Adafruit_LIS3MDL lis3mdl;
Adafruit_GPS GPS(&Wire);
Adafruit_Mahony filter;

// Settings
#define FILTER_UPDATE_RATE_HZ 100
#define GPSECHO false

// Globals
File logFile;
String fileName = "data.csv";
uint32_t last_filter_update = 0;

void setup() {
  Serial.begin(115200);
  // while (!Serial) delay(10); // Uncomment to wait for serial console

  Wire.begin();

  // Initialize BMP390
  if (!bmp.begin_I2C()) {
    Serial.println("BMP390 not found!");
    while (1) delay(10);
  }
  bmp.setTemperatureOversampling(BMP3_OVERSAMPLING_8X);
  bmp.setPressureOversampling(BMP3_OVERSAMPLING_4X);
  bmp.setIIRFilterCoeff(BMP3_IIR_FILTER_COEFF_3);
  bmp.setOutputDataRate(BMP3_ODR_50_HZ);

  // Initialize LSM6DSOX
  if (!sox.begin_I2C()) {
    Serial.println("LSM6DSOX not found!");
    while (1) delay(10);
  }
  sox.setAccelRange(LSM6DS_ACCEL_RANGE_4_G);
  sox.setGyroRange(LSM6DS_GYRO_RANGE_2000_DPS);
  sox.setAccelDataRate(LSM6DS_RATE_104_HZ);
  sox.setGyroDataRate(LSM6DS_RATE_104_HZ);

  // Initialize LIS3MDL
  if (!lis3mdl.begin_I2C()) {
    Serial.println("LIS3MDL not found!");
    while (1) delay(10);
  }
  lis3mdl.setDataRate(LIS3MDL_DATARATE_155_HZ);
  lis3mdl.setRange(LIS3MDL_RANGE_4_GAUSS);
  lis3mdl.setPerformanceMode(LIS3MDL_MEDIUMMODE);
  lis3mdl.setOperationMode(LIS3MDL_CONTINUOUSMODE);

  // Initialize GPS
  GPS.begin(0x10); // Default I2C address
  GPS.sendCommand(PMTK_SET_NMEA_OUTPUT_RMCGGA);
  GPS.sendCommand(PMTK_SET_NMEA_UPDATE_10HZ);
  GPS.sendCommand(PGCMD_ANTENNA);

  // Initialize AHRS
  filter.begin(FILTER_UPDATE_RATE_HZ);

  // Initialize SD Card
  // Uses default SS pin for the board variant
  if (!SD.begin()) {
    Serial.println("SD Card failed!");
  } else {
    // Create unique file
    for (int i = 0; i < 1000; i++) {
      fileName = "log" + String(i) + ".csv";
      if (!SD.exists(fileName)) break;
    }
    logFile = SD.open(fileName, FILE_WRITE);
    if (logFile) {
      logFile.println("ms,qw,qx,qy,qz,ax,ay,az,gx,gy,gz,mx,my,mz,alt,gps_fix,lat,lon,speed,heading");
      logFile.flush();
      Serial.print("Logging to: "); Serial.println(fileName);
    }
  }
}

void loop() {
  // Read GPS
  GPS.read();
  if (GPS.newNMEAreceived()) {
    GPS.parse(GPS.lastNMEA());
  }

  // Main Loop @ 100Hz
  if (millis() - last_filter_update >= (1000 / FILTER_UPDATE_RATE_HZ)) {
    last_filter_update = millis();

    // Read IMU
    sensors_event_t accel, gyro, temp, mag;
    sox.getEvent(&accel, &gyro, &temp);
    lis3mdl.getEvent(&mag);

    // Update Filter (Gyro in deg/s for Mahony)
    float gx_deg = gyro.gyro.x * SENSORS_RADS_TO_DPS;
    float gy_deg = gyro.gyro.y * SENSORS_RADS_TO_DPS;
    float gz_deg = gyro.gyro.z * SENSORS_RADS_TO_DPS;

    filter.update(gx_deg, gy_deg, gz_deg,
                  accel.acceleration.x, accel.acceleration.y, accel.acceleration.z,
                  mag.magnetic.x, mag.magnetic.y, mag.magnetic.z);

    // Read Altitude
    bmp.performReading();

    // Build CSV String
    String data = "";
    data += String(millis()) + ",";

    // Quaternion
    float qw, qx, qy, qz;
    filter.getQuaternion(&qw, &qx, &qy, &qz);
    data += String(qw, 4) + "," + String(qx, 4) + "," + String(qy, 4) + "," + String(qz, 4) + ",";

    // Accel (m/s^2)
    data += String(accel.acceleration.x, 2) + "," + String(accel.acceleration.y, 2) + "," + String(accel.acceleration.z, 2) + ",";

    // Gyro (rad/s)
    data += String(gyro.gyro.x, 4) + "," + String(gyro.gyro.y, 4) + "," + String(gyro.gyro.z, 4) + ",";

    // Mag (uT)
    data += String(mag.magnetic.x, 2) + "," + String(mag.magnetic.y, 2) + "," + String(mag.magnetic.z, 2) + ",";

    // Altitude (m)
    data += String(bmp.readAltitude(1013.25), 2) + ",";

    // GPS
    data += String(GPS.fix) + ",";
    if (GPS.fix) {
      data += String(GPS.latitudeDegrees, 6) + "," + String(GPS.longitudeDegrees, 6) + ",";
      data += String(GPS.speed) + "," + String(GPS.angle);
    } else {
      data += "0.0,0.0,0.0,0.0";
    }

    // Output
    Serial.println(data);
    if (logFile) {
      logFile.println(data);
      
      // Flush periodically (e.g. every 1 second)
      static int flushCounter = 0;
      if (flushCounter++ > FILTER_UPDATE_RATE_HZ) {
        logFile.flush();
        flushCounter = 0;
      }
    }
  }
}

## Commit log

2026-01-30 Adding initial raw data capturing & visualization in MATLAB. Test file included
    [test_data.csv]
2026-01-30 added streamlit viz
    [kitti_sample_01_start.csv, kitti_sample_02_early.csv, kitti_sample_03_morning.csv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]
2026-01-30 Restructured files, removed unnessecary files, added boards, modified paths, fixed analysis code to use new example format
    [4517_LSM6DSOX_LIS3MDL.step, 4816_BMP390_QT.step, 5980_Feather_RP2040_Adalogger.step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]
2026-01-31 Updated readme, added different firmwares for different outputs, added new analyzer scripts for various firmware outputs
    [example_format_quat.csv, example_format_raw.csv]
2026-02-03 Updated firmware for SD, performed first live test, added Mahony filter option as default w/ Magdwick, updated readme, new firmware version for testing, sd card testing file
    [example_format_quat_serial.csv, example_format_raw_serial.csv]
2026-02-07 First prototype of enclosure, slightly changed SD card tester.
    [enclosure-r1.SLDPRT, enclosure-r1.STEP, log0.csv]
2026-02-07 Final prototype for v0.1
2026-02-07 v0.2 Initial commit: - Consolidated all logging to a single, good algorithm. - Added more filtering to add accuracy, along with explicit calibration instructions. - Made README more readable and more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
    [enclosure-r1.SLDPRT, enclosure-r1.STEP, example_format_quat.csv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]
2026-02-07 v0.2 Update: - Added r1 enclosure to showcase build. Future improvements soon to follow
2026-02-08 v0.2 Update: - Added files for automating calibration. - configuration.cfg now used for setting 9-dof calibration constants. - Updated readme to reflect changes.
    [log0.csv]
2026-02-08 v0.2 Update: - Added RTC calibration in a more intelligent fashion.
2026-02-08 v0.2 Update: - Added adaptive accelerometer rejection to allow for better gyroscopic orientation tracking when higher g-forces are experienced. - Added LPF2 hardware filtering from LSM6DSOX thanks to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
2026-02-11 v0.2 Update: - Added Enclosure version r2 to the repo. Includes full case for better protection and better battery mounting.
    [assembly.SLDASM, base.SLDPRT, base.STEP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]
2026-02-11 v0.2 Update: - Added more visualization options to live visualizer and improved UI. - Enclosure r2 removes the hardware dependecny for the RTC. Edited the code to temporarily remove the usage for fut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
    [enclosure_r2_ph.stl]
2026-02-11 v0.2 Update: - Added new images for R2 enclosure to readme.
2026-02-13 v0.2 Final: - New parts came in, this is being deprecated. - Fixed GPS, uses UTC now. - Finalized readme for this iteration
    [quat_datalogger.ino]
